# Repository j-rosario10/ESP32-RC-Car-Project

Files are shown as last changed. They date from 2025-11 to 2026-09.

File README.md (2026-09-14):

# BMW M2 RC Car

An ESP32-based RC vehicle inspired by the BMW M2 Competition, combining mechanical design, embedded motor control, and a game-style web dashboard into a single mechatronics system.

---

## 🔧 Technical Overview

- Designed a custom BMW M2-inspired chassis in SolidWorks, accounting for motor mounting, steering geometry, electronics placement, and manufacturability, then validated the structure with FEA before printing.
- Implemented dual DC motor drive and steering servo control using an ESP32, H-bridge motor drivers, and PWM control logic programmed in Arduino C++.
- Added a torque vectoring layer that biases drive torque between the left and right motors based on steering input, tightening corner entry without a mechanical differential.
- Implemented regenerative braking that shorts the motor terminals through the H-bridge under deceleration, recovering energy back into the pack instead of coasting or hard-braking.
- Developed an ESP32-hosted web dashboard using HTML, CSS, and JavaScript for real-time wireless vehicle control and live telemetry.
- Integrated ultrasonic obstacle detection directly into the motor control loop to automatically prevent collisions during forward motion.
  
---

## ⚙️ Key Features

- Independent left and right motor control with real-time differential steering and smooth acceleration and braking behaviour.
- Steering-dependent torque vectoring, with the bias curve exposed as a tunable parameter rather than hardcoded.
- Regenerative braking on throttle release and on brake input, with the recovered current visible live on the dashboard.
- Fail-safe stop logic that halts the vehicle when control input is released or the connection is lost.
- Ultrasonic obstacle detection that continuously monitors distance ahead and blocks forward motion within a safety threshold.
- ESP32-hosted, game-style dashboard with live speed visualization, steering indicators, drive state feedback, and pedal-style controls.
- Drift mode toggle that increases steering aggressiveness and relaxes the torque bias, reflected visually in the dashboard.
- Modular ESP32-CAM integration providing live video feedback without impacting motor responsiveness.
- Lightweight, non-blocking networking architecture using REST-style endpoints for control and telemetry.

---

## 📸 Project Media

<p align="center">
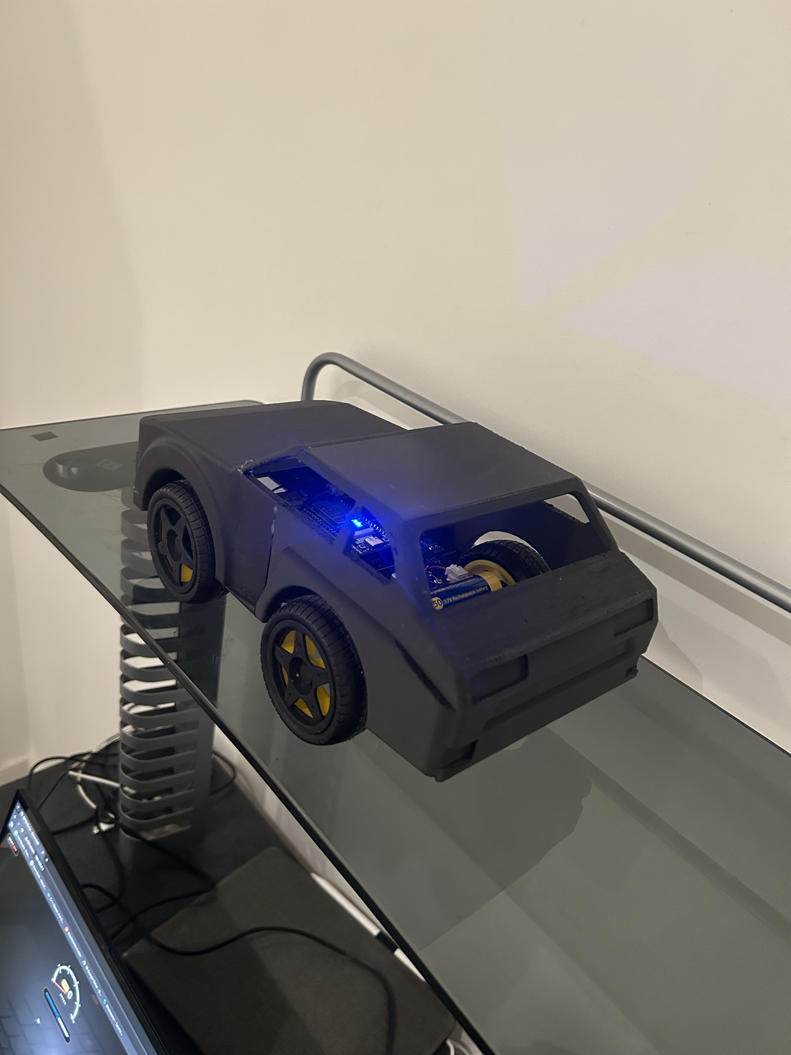
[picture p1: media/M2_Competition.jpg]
  
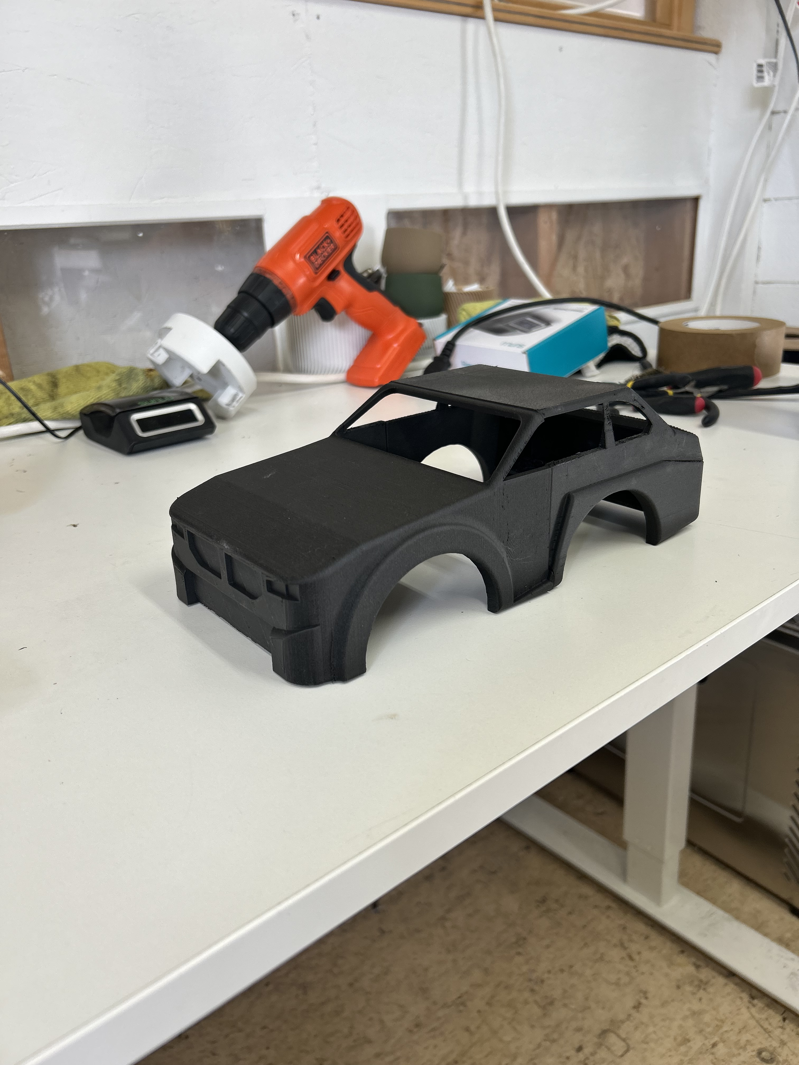
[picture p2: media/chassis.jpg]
  
</p>

<p align="center">
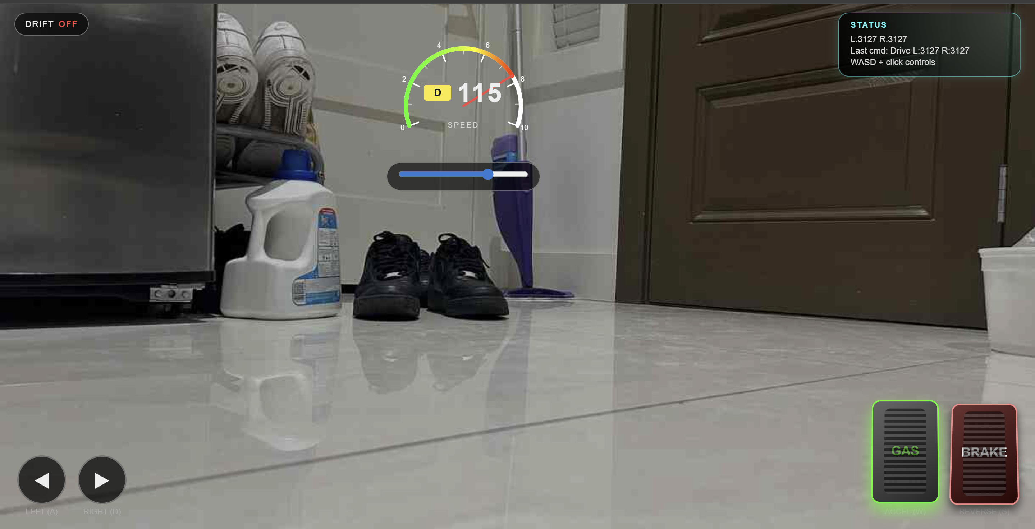
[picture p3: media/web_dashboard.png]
  
</p>

<p align="center">
  <i>BMW M2 inspired exterior, SolidWorks chassis design, and full screen web based control dashboard</i>
</p>

---

## 🎥 Video Demonstration

The video below shows live driving, dashboard interaction, steering response, and integrated obstacle detection.

▶ **Watch the RC Car Demonstration Video**  
https://drive.google.com/file/d/1aE3MejNEvwfQ_U80hKvikGiKrMmLiO1q/view?usp=sharing

---

## 🧠 System Architecture

- Mechanical  
  SolidWorks CAD chassis designed for compact packaging and structural rigidity, checked under load with FEA and printed in-house.

- Embedded  
  ESP32 microcontroller handling motor control, torque distribution, regenerative braking, sensing, networking, and camera streaming.

- Software  
  Modular C++ codebase developed in VS Code with PlatformIO, separating vehicle control, torque and brake logic, dashboard logic, and camera handling.

- Networking  
  ESP32 configured as a self-contained Wi-Fi access point with HTTP endpoints for control, telemetry, and video streaming.

---

## 🚀 Future Improvements

- Closed-loop speed control using wheel encoders, which would also let the regen braking target a set deceleration rate instead of a fixed duty.
- Vision-based obstacle detection using the onboard camera.
- Autonomous navigation behaviours built on the existing safety logic.
- Mobile-optimized dashboard layout.

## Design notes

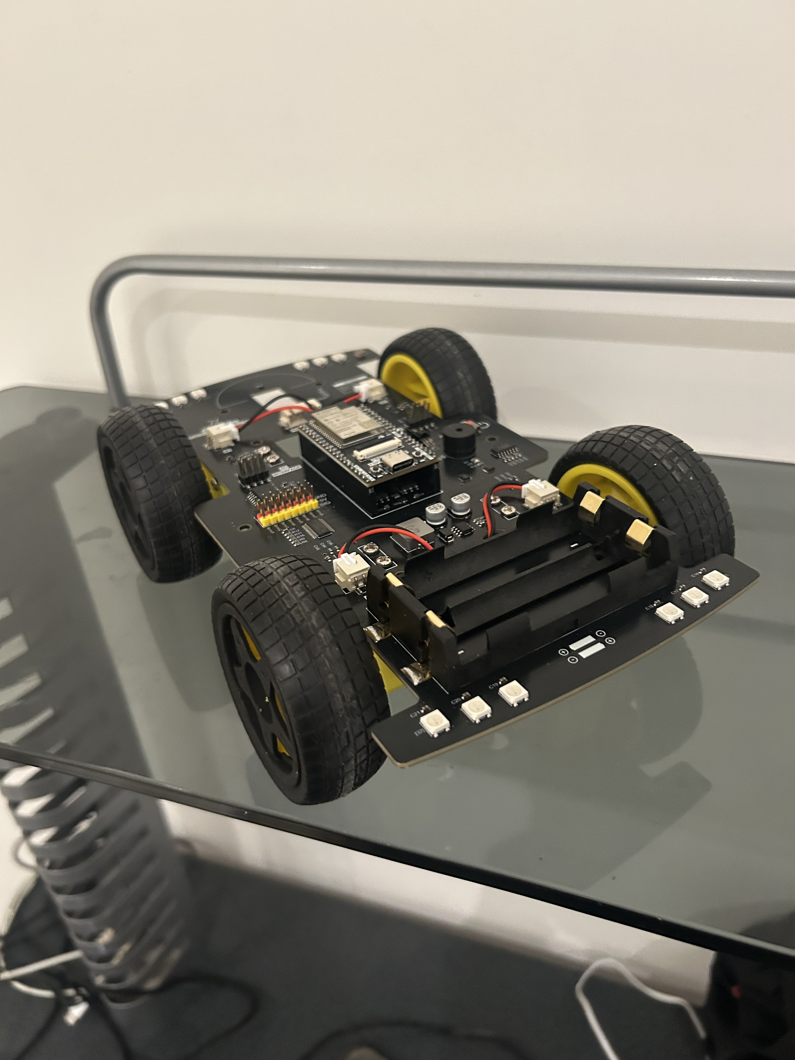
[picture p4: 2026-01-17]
media/hardware.jpg

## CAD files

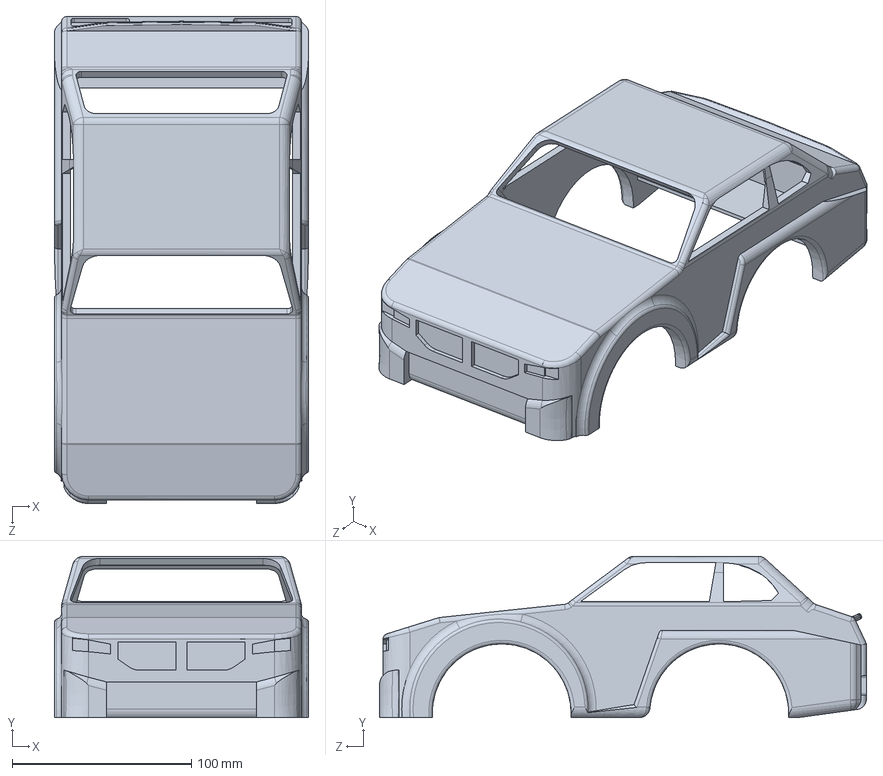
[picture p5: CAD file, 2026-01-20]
CAD/RC Car Shell_V2.SLDPRT
142.0 x 90.1 x 272.0 mm

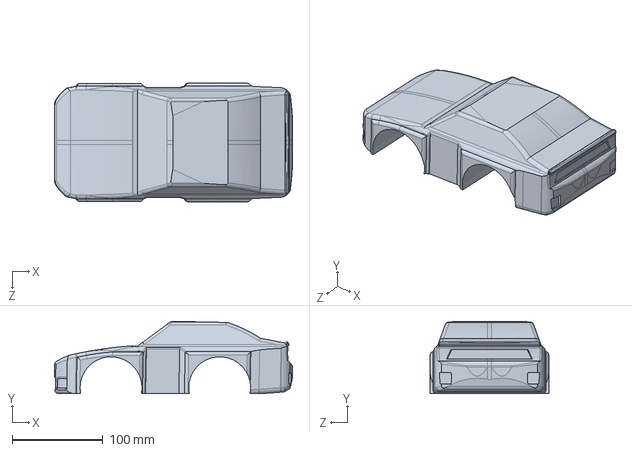
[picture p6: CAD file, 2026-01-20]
CAD/RC Car Shell.SLDPRT
261.9 x 79.8 x 130.5 mm

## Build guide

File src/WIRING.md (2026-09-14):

# Wiring and bring-up

## The shared bus

GPIO 13 and 14 already run to the PCA9685. The gyro and current sensor join
those same two wires. You are not adding new pins for either sensor.

Each chip has a different address so they don't collide:

| Chip | Address |
|---|---|
| PCA9685 (motors) | 0x5F |
| MPU6050 (gyro) | 0x68 |
| INA226 (current) | 0x40 |

## MPU6050 gyro

| Pin | To |
|---|---|
| VCC | **3.3V** — not 5V |
| GND | GND |
| SDA | GPIO 13 |
| SCL | GPIO 14 |
| AD0 | GND, or leave it |

Mount it flat, near the middle of the car, Z axis pointing up, and screw it
down properly. Foam tape lets it vibrate and motor buzz shows up as fake
rotation in the readings.

**Before trusting it:** uncomment `Sensors::gyroSignTest()` in `setup()`,
flash, and rotate the car by hand. One direction should be consistently
positive, the other consistently negative. If it's backwards, change
`GYRO_Z_SIGN` to `-1.0f` in `config.h`. Don't remount the chip.

## INA226 current sensor

This one goes *in* the power path, not on a header. Cut the positive battery
wire and put the sensor in the gap:

```
Battery + ──→ [IN+]  INA226  [IN−] ──→ board power in
```

IN+ faces the battery, IN− faces the car. Backwards and charging reads as
draining.

| Pin | To |
|---|---|
| VCC | 3.3V |
| GND | GND |
| SDA | GPIO 13 |
| SCL | GPIO 14 |

**Check your shunt.** Lots of cheap boards ship with a 0.1 ohm shunt rated
under 1A, which four motors will cook. Get 0.01 ohm or lower, then put the
real value in `SHUNT_OHMS` in `config.h`. Wrong value means every reading is
wrong by the same factor, silently.

## DRV8871 regen driver

One motor only. Leave the other three on the PCA9685 so the car still drives
normally while you experiment.

| Pin | To |
|---|---|
| IN1 | GPIO 25 |
| IN2 | GPIO 26 |
| VM | Battery + (downstream of the INA226) |
| GND | GND |
| OUT1 / OUT2 | The motor's two wires |

Unplug that motor from the old driver first. One motor, one driver, never both.

Avoid GPIO 0, 2, 12 and 15 if you change pins — the ESP32 reads those at boot
and pulling them wrong stops it starting. 25, 26, 27, 32 are safe.

## Bring-up order

Flash and test after each step rather than doing it all at once.

1. **Code only, no new parts.** Motor braking and 1000Hz PWM work with the
   hardware you already have. Confirm the car stops hard instead of lurching
   into reverse.
2. **Gyro.** Run the sign test. Then set `YAW_KP = 0` in `config.h` and drive —
   watch target vs actual on the dashboard without any correction happening.
   Only once those numbers look sane, raise KP.
3. **Current sensor.** Watch live watts while driving. Accelerating should be
   a big positive number, coasting near zero. Confirm the sign before you
   trust the energy totals.
4. **Regen driver.** Test at low speed, at about half battery charge, watching
   pack voltage. If it climbs past 8.3V, stop.

## Tuning YAW_KP

Start at 0. Raise it in steps of about 0.001. When the car starts weaving side
to side on a straight, you've gone too far — drop back about 30%.

`YAW_TARGET_GAIN` is the other knob. If actual yaw never gets anywhere near
target even at full correction, the target is unrealistic — lower it.

## Watch the overrun counter

The dashboard shows how many times the loop missed its 5ms slot. A handful at
startup is fine. If it climbs steadily while driving, the loop is doing more
work than it has time for — usually I2C traffic. Drop `LOOP_HZ` to 100 or read
the gyro every other cycle.

## Safety

- Regen testing at half charge, never straight off the charger.
- Watch pack voltage. Two full cells sit at 8.4V and pushing above that is
  not safe.
- The failsafe stops the car if the browser goes quiet for 300ms. Test it
  early — drive slowly, close the tab, confirm the car stops.

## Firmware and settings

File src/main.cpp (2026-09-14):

// BMW M2 RC car - ESP32 firmware
//
// Sections in order:
//   1  config     temp numbers
//   2  motors     talking to the motor chip, including braking
//   3  sensors    gyro and battery current
//   4  regen      the fast switching that charges the battery while braking
//   5  control    the loop that runs 200 times a second and does the driving
//   6  web        the Wi-Fi network and the web page
//
// The big idea: the browser does NOT drive the car. It only reports which
// keys you're holding. All the actual decisions happen in section 5, on the
// ESP32. That's because Wi-Fi delay is unpredictable - a message might take
// 5 milliseconds or 200 - and anything automatic needs steady timing.

#include <Arduino.h>
#include <Wire.h>
#include <WiFi.h>
#include <WebServer.h>
#include <PCA9685.h>
#include <Adafruit_MPU6050.h>
#include <Adafruit_Sensor.h>
#include <INA226.h>

#include "page.h"

// ===========================================================================
// 1  CONFIG
// ===========================================================================

// These two pins are fixed by the Freenove board, so don't change them.
// All three chips share the same two wires and take turns talking.
static constexpr int I2C_SDA = 13;
static constexpr int I2C_SCL = 14;
static constexpr uint32_t I2C_CLOCK_HZ = 400000;   // 4x the default speed,
                                                   // because chatting to the
                                                   // chips is the slowest part
                                                   // of each loop

// Each chip has its own address so the ESP32 knows who it's talking to.
static constexpr uint8_t ADDR_PCA9685 = 0x5F;
static constexpr uint8_t ADDR_MPU6050 = 0x68;
static constexpr uint8_t ADDR_INA226  = 0x40;

// The kit sets this to 50 because it shares the chip with steering servos.
// We have no servos, so we can turn it right up. Smoother, and free.
static constexpr int MOTOR_PWM_FREQ = 1000;
static constexpr int MOTOR_MAX = 4095;             // full speed

// Don't use pins 0, 2, 12 or 15 - the ESP32 checks those when it starts up
// and pulling them the wrong way stops it booting.
static constexpr int REGEN_IN1_PIN = 25;
static constexpr int REGEN_IN2_PIN = 26;
static constexpr int REGEN_PWM_FREQ = 20000;       // 20,000 switches a second.
                                                   // Too fast to hear, and fast
                                                   // enough for the pumping
                                                   // trick to work.
static constexpr int REGEN_PWM_BITS = 10;

// How many times a second the control loop runs. 200 was chosen because it's
// as fast as we can go before talking to the chips takes too long.
static constexpr int   LOOP_HZ = 200;
static constexpr float LOOP_DT = 1.0f / LOOP_HZ;   // 5 milliseconds
static constexpr uint32_t INPUT_TIMEOUT_MS = 300;  // silence this long = stop

// A key is only on or off, but steering is an amount. So we use TIME as the
// missing information: tap for a little, hold for a lot.
// Letting go is faster than holding, so the car straightens up promptly.
static constexpr float STEER_RISE_RATE = 2.0f;     // half a second to full lock
static constexpr float STEER_FALL_RATE = 4.0f;
static constexpr float THROTTLE_RISE_RATE = 1.5f;
static constexpr float THROTTLE_FALL_RATE = 2.5f;
static constexpr float BRAKE_RISE_RATE = 3.0f;
static constexpr float BRAKE_FALL_RATE = 6.0f;

// Drift mode just lets the steering build up further than normal.
static constexpr float STEER_LIMIT_NORMAL = 0.60f;
static constexpr float STEER_LIMIT_DRIFT  = 1.00f;

// How fast the car should spin around at full steering and full speed,
// in degrees per second. Found by driving it and seeing what it can do.
static constexpr float YAW_TARGET_GAIN = 180.0f;

// How hard the car corrects itself. START AT 0 and raise it slowly. When the
// car starts weaving side to side on a straight, that's too much - back off.
static constexpr float YAW_KP = 0.004f;

// The most the car is allowed to correct. Without this, on a slippery floor
// it would push harder and harder and just spin on the spot.
static constexpr float YAW_CORRECTION_LIMIT = 0.45f;

// Whether "turning right" reads as a positive or negative number depends on
// which way up you mounted the gyro. Run the test in setup(), and if it's
// backwards change this to -1.0f. Easier than remounting the chip.
static constexpr float GYRO_Z_SIGN = 1.0f;

// Anything smaller than this is just the motors shaking the car, not the car
// actually turning. Ignoring it stops the controller twitching.
static constexpr float GYRO_DEADBAND_DPS = 1.5f;

// There are no encoders on this car, so we can't measure speed. Instead we
// guess: assume the car catches up to the throttle with a delay. It's wrong
// if the wheels spin, but we only need a rough fast-or-slow.
static constexpr float SPEED_RISE_TAU = 0.8f;      // seconds to get up to speed
static constexpr float SPEED_FALL_TAU = 1.2f;      // coasts down slower
static constexpr float SPEED_BRAKE_TAU = 0.4f;     // braking drops it fast

// Two lithium cells fully charged sit at 8.4V. A full battery has no room for
// more charge, so we stop regen before we get there. Real electric cars do
// the same thing - it's why regen feels weak right after charging.
static constexpr float PACK_REGEN_CUTOFF_VOLTS = 8.30f;

// CHECK YOUR BOARD. Lots of cheap current sensors come with a 0.1 ohm shunt
// rated for under 1 amp, and four motors will cook it. You want 0.01 or less.
// If this number doesn't match your board, every reading is wrong.
static constexpr float SHUNT_OHMS = 0.010f;
static constexpr float SHUNT_MAX_AMPS = 8.0f;

// The car makes its own Wi-Fi network, so it works anywhere with no router.
static const char* AP_SSID = "ESP32-RC-Car";
static const char* AP_PASS = "";

// ===========================================================================
// 2  MOTORS
// ===========================================================================

// These are channel numbers on the PCA9685 chip, NOT ESP32 pins. Easy to mix
// up. Each motor uses two channels, because the driver needs two signals to
// know both how fast to go and which direction.
static constexpr uint8_t M1_IN1 = 15, M1_IN2 = 14;
static constexpr uint8_t M2_IN1 = 9,  M2_IN2 = 8;
static constexpr uint8_t M3_IN1 = 12, M3_IN2 = 13;
static constexpr uint8_t M4_IN1 = 10, M4_IN2 = 11;

// If a wheel spins the wrong way after you rewire something, flip its
// number to -1 here instead of changing any logic.
static constexpr int M1_DIR = 1, M2_DIR = 1, M3_DIR = 1, M4_DIR = 1;

static PCA9685 pca;

// Remembers what we last sent to each channel. Talking to the motor chip is
// slow, and most of the time only a couple of channels actually change, so
// skipping the rest gives us back a big chunk of each loop.
static int lastWritten[16];

static int clampMotor(int s) {
    if (s < -MOTOR_MAX) return -MOTOR_MAX;
    if (s >  MOTOR_MAX) return  MOTOR_MAX;
    return s;
}

static void writeChannel(uint8_t ch, int value) {
    if (lastWritten[ch] == value) return;      // nothing changed, skip it
    pca.setChannelPulseWidth(ch, value);
    lastWritten[ch] = value;
}

// The motor driver has four possible states, and the original code only ever
// used three of them:
//
//   speed / 0        forward
//   0 / speed        reverse
//   0 / 0            coast - motor spins freely
//   high / high      BRAKE - the two motor wires get joined together
//
// That last one is the whole trick behind motor braking. You don't connect
// any wires yourself. The switches are already inside the chip - the old code
// just never asked for them.
static void driveChannels(uint8_t in1, uint8_t in2, int speed) {
    speed = clampMotor(speed);

    if (speed >= 0) { writeChannel(in1, speed);  writeChannel(in2, 0); }
    else            { writeChannel(in1, 0);      writeChannel(in2, -speed); }
}

// Sending the same value to both inputs joins the motor wires together.
// At full value it's permanently joined and brakes hard. At half, it spends
// half its time joined and half coasting, which gives about half the braking.
// That's how you get a brake with pressure levels out of an on/off chip.
static void brakeChannels(uint8_t in1, uint8_t in2, int strength) {
    if (strength < 0) strength = -strength;
    if (strength > MOTOR_MAX) strength = MOTOR_MAX;

    writeChannel(in1, strength);
    writeChannel(in2, strength);
}

// m1 and m2 are the right side. m3 and m4 are the left side.
static void motorsMove(int m1, int m2, int m3, int m4) {
    driveChannels(M1_IN1, M1_IN2, M1_DIR * clampMotor(m1));
    driveChannels(M2_IN1, M2_IN2, M2_DIR * clampMotor(m2));
    driveChannels(M3_IN1, M3_IN2, M3_DIR * clampMotor(m3));
    driveChannels(M4_IN1, M4_IN2, M4_DIR * clampMotor(m4));
}

static void motorsBrake(int strength) {
    brakeChannels(M1_IN1, M1_IN2, strength);
    brakeChannels(M2_IN1, M2_IN2, strength);
    brakeChannels(M3_IN1, M3_IN2, strength);
    brakeChannels(M4_IN1, M4_IN2, strength);
}

static void motorsBegin() {
    for (int i = 0; i < 16; i++) lastWritten[i] = -1;   // force the first write

    Wire.begin(I2C_SDA, I2C_SCL);
    Wire.setClock(I2C_CLOCK_HZ);

    // The motor chip powers up asleep. This wakes it. The library is supposed
    // to do this but it doesn't always work, so we do it by hand first.
    Wire.beginTransmission(ADDR_PCA9685);
    Wire.write(0x00);
    Wire.write(0x00);
    Wire.endTransmission();

    pca.setupSingleDevice(Wire, ADDR_PCA9685);
    pca.setToFrequency(MOTOR_PWM_FREQ);

    motorsMove(0, 0, 0, 0);
}

// ===========================================================================
// 3  SENSORS
// ===========================================================================
// Both sensors are optional. If one isn't plugged in, the car still drives -
// it just turns off the feature that needed it, instead of refusing to start.

static Adafruit_MPU6050 mpu;
static INA226 ina(ADDR_INA226, &Wire);

static bool gyroOK = false, inaOK = false;
static float gyroZeroOffset = 0.0f;     // the gyro's own built-in error
static float yawRateDps = 0.0f;         // how fast the car is turning
static float packV = 0.0f, packA = 0.0f, packW = 0.0f;
static float joulesOut = 0.0f, joulesIn = 0.0f;

// We only read the current sensor every 10th loop, so 20 times a second.
// Reading it is slow, and battery current doesn't change much in 5ms anyway.
static uint8_t inaSkip = 0;
static uint32_t lastEnergyUs = 0;

static void sensorsBegin() {
    // The two wires are already switched on by motorsBegin(), so we just
    // join the conversation. That's why the order in setup() matters.

    if (mpu.begin(ADDR_MPU6050, &Wire)) {
        gyroOK = true;

        // The narrowest range the chip offers. The car never turns faster
        // than this, and a narrow range means finer detail on small numbers -
        // which is exactly what the controller reacts to.
        mpu.setGyroRange(MPU6050_RANGE_250_DEG);
        mpu.setAccelerometerRange(MPU6050_RANGE_4_G);

        // A smoothing filter inside the chip. 21Hz is the sweet spot: enough
        // to hide motor vibration, not so much that readings arrive late.
        // Late readings make the controller unstable.
        mpu.setFilterBandwidth(MPU6050_BAND_21_HZ);

        Serial.println("[sensors] MPU6050 found");
    } else {
        Serial.println("[sensors] no MPU6050 - torque vectoring disabled");
    }

    if (ina.begin()) {
        inaOK = true;
        ina.setMaxCurrentShunt(SHUNT_MAX_AMPS, SHUNT_OHMS);
        Serial.println("[sensors] INA226 found");
    } else {
        Serial.println("[sensors] no INA226 - regen will run blind");
    }

    lastEnergyUs = micros();
}

// Every gyro reports a small wrong number even when perfectly still, and it's
// different for every chip. So we sit still, take 500 readings, average them,
// and subtract that from everything afterwards.
//
// One reading isn't enough because the noise is about the same size as the
// error we're trying to find. Averaging cancels the noise out.
//
// THE CAR MUST BE STILL while this runs.
static void calibrateGyro(uint16_t samples = 500) {
    if (!gyroOK) return;

    Serial.println("[sensors] calibrating - keep the car still");

    double sum = 0.0;
    for (uint16_t i = 0; i < samples; i++) {
        sensors_event_t a, g, t;
        mpu.getEvent(&a, &g, &t);
        sum += g.gyro.z;
        delay(3);
    }

    // The library gives radians per second; we want degrees per second.
    gyroZeroOffset = (float)(sum / samples) * 57.2958f;

    Serial.print("[sensors] gyro offset: ");
    Serial.print(gyroZeroOffset, 3);
    Serial.println(" deg/s");
}

static void sensorsUpdate() {
    if (gyroOK) {
        sensors_event_t a, g, t;
        mpu.getEvent(&a, &g, &t);

        float dps = (g.gyro.z * 57.2958f) - gyroZeroOffset;
        dps *= GYRO_Z_SIGN;

        // Tiny readings are the motors shaking the car, not the car turning.
        if (dps > -GYRO_DEADBAND_DPS && dps < GYRO_DEADBAND_DPS) dps = 0.0f;

        yawRateDps = dps;
    }

    if (inaOK) {
        if (++inaSkip >= 10) {
            inaSkip = 0;
            packV = ina.getBusVoltage();
            packA = ina.getCurrent();      // negative means charging
            packW = packV * packA;
        }

        // Energy is just power multiplied by time, added up as we go.
        // We do this every loop, even though the reading only updates every
        // 10th, so the time part stays accurate.
        uint32_t now = micros();
        float dt = (now - lastEnergyUs) / 1000000.0f;
        lastEnergyUs = now;

        // The microsecond timer wraps around every 70 minutes and gives a
        // nonsense value when it does. This throws that one reading away.
        if (dt > 0.0f && dt < 0.5f) {
            if (packW > 0) joulesOut += packW * dt;
            else           joulesIn  += (-packW) * dt;
        }
    }
}

// Run this once after mounting the gyro. Rotate the car by hand and watch the
// numbers: one direction should be positive, the other negative. If it's
// backwards, change GYRO_Z_SIGN above rather than remounting the chip.
static void gyroSignTest() {
    if (!gyroOK) { Serial.println("[test] no gyro"); return; }

    Serial.println("[test] rotate the car by hand for 10s");

    uint32_t until = millis() + 10000;
    while (millis() < until) {
        sensorsUpdate();
        Serial.print("yaw: ");
        Serial.print(yawRateDps, 1);
        Serial.println(" deg/s");
        delay(100);
    }
}

// ===========================================================================
// 4  REGEN
// ===========================================================================
// This section exists because the motor chip is too slow. It can switch about
// 1,500 times a second. Regen needs about 20,000. The ESP32 itself can do
// that easily, so one motor gets its own driver board wired straight to two
// ESP32 pins, skipping the slow chip entirely.
//
// How the charging works:
//
//   Both pins HIGH -> the motor's two wires are joined together. Electricity
//                     builds up inside the motor's coil. The battery isn't
//                     part of this at all yet.
//
//   Both pins LOW  -> the connection breaks. That built-up electricity has
//                     nowhere to go, so it forces itself out at a higher
//                     voltage - high enough to reach the battery.
//
// Build, release, build, release, 20,000 times a second. It's a pump. How
// much of each cycle is spent building is how hard you brake.
//
// Both pins get the exact same signal, which is why this is only a few lines.

static constexpr int REGEN_CH1 = 4;    // channels 0-3 are often used by other
static constexpr int REGEN_CH2 = 5;    // libraries, so we start at 4
static constexpr int REGEN_DUTY_MAX = (1 << REGEN_PWM_BITS) - 1;

static void regenWrite(int duty) {
#if ESP_ARDUINO_VERSION_MAJOR >= 3
    ledcWrite(REGEN_IN1_PIN, duty);
    ledcWrite(REGEN_IN2_PIN, duty);
#else
    ledcWrite(REGEN_CH1, duty);
    ledcWrite(REGEN_CH2, duty);
#endif
}

// duty is 0 to 1, and more is NOT always better:
//   0.0   coasting, nothing happens
//   0.3   light braking, and most of the energy reaches the battery
//   1.0   the motor stays joined the whole time, so it brakes hard but the
//         electricity never gets released - all drag, no charge
// The useful range is about 0.2 to 0.7, which is why the controller caps it.
static void regenSetDuty(float duty) {
    if (duty < 0.0f) duty = 0.0f;
    if (duty > 1.0f) duty = 1.0f;
    regenWrite((int)(duty * REGEN_DUTY_MAX));
}

static void regenCoast() { regenWrite(0); }

static void regenBegin() {
    // Newer versions of the ESP32 software renamed these functions, so we
    // handle both. Saves you a confusing error if you update.
#if ESP_ARDUINO_VERSION_MAJOR >= 3
    ledcAttach(REGEN_IN1_PIN, REGEN_PWM_FREQ, REGEN_PWM_BITS);
    ledcAttach(REGEN_IN2_PIN, REGEN_PWM_FREQ, REGEN_PWM_BITS);
#else
    ledcSetup(REGEN_CH1, REGEN_PWM_FREQ, REGEN_PWM_BITS);
    ledcSetup(REGEN_CH2, REGEN_PWM_FREQ, REGEN_PWM_BITS);
    ledcAttachPin(REGEN_IN1_PIN, REGEN_CH1);
    ledcAttachPin(REGEN_IN2_PIN, REGEN_CH2);
#endif
    regenCoast();
}

// ===========================================================================
// 5  CONTROL
// ===========================================================================

// What the browser sends us: which keys are held down. Not motor commands.
// The old version had the browser do the maths and send finished numbers,
// which meant the driving decisions were being made on the far side of a
// Wi-Fi connection. Fine for a person pressing keys, useless for anything
// that has to react to the car.
struct Input {
    bool w = false, a = false, s = false, d = false, drift = false;
    uint32_t lastSeenMs = 0;
};

// Everything the loop works out gets published here, not just what the
// dashboard shows. Being able to log what the car wanted versus what it did
// is how you tune the controller and how you measure the regen.
struct Telemetry {
    float steer, throttle, brake, speedEst;
    float yawTarget, yawActual, yawError, correction;
    float volts, amps, watts, joulesOut, joulesIn;
    uint32_t overruns;
    bool failsafe;
};

// Two parts of the program touch these at the same time, so they need
// protecting or you get half-updated values. This is the quick kind of lock -
// the web page must never be able to hold up the motors.
static portMUX_TYPE stateMux = portMUX_INITIALIZER_UNLOCKED;
static Input     sharedInput;
static Telemetry sharedTelem;

// Only the control loop touches these, so they don't need protecting.
static float steer = 0.0f, throttle = 0.0f, brake = 0.0f, speedEst = 0.0f;
static uint32_t overrunCount = 0;

// Moves a value a little bit toward a target, without overshooting it.
static float rampToward(float value, float target, float rate, float dt) {
    float step = rate * dt;

    if (value < target)      { value += step; if (value > target) value = target; }
    else if (value > target) { value -= step; if (value < target) value = target; }
    return value;
}

// HOLD TO BUILD
// A key is on or off, but steering is an amount. So we use how long you hold
// it: tap for a little, hold for a lot.
//
// This has to happen here on the car, not in the browser. If the browser did
// the ramping, every step of it would have to travel over Wi-Fi, and the ramp
// would end up as jerky as the connection.
static void updateInputs(const Input& in) {
    float limit = in.drift ? STEER_LIMIT_DRIFT : STEER_LIMIT_NORMAL;

    // Letting go fades faster than holding builds, so the car straightens up
    // quickly instead of carrying steering into whatever you do next.
    if (in.a && !in.d)      steer = rampToward(steer, -limit, STEER_RISE_RATE, LOOP_DT);
    else if (in.d && !in.a) steer = rampToward(steer,  limit, STEER_RISE_RATE, LOOP_DT);
    else                    steer = rampToward(steer,  0.0f,  STEER_FALL_RATE, LOOP_DT);

    // S is a proper brake now. It used to subtract from throttle, which meant
    // pressing brake actually commanded reverse - spending battery power to
    // fight the motors instead of taking power out of them.
    throttle = in.w ? rampToward(throttle, 1.0f, THROTTLE_RISE_RATE, LOOP_DT)
                    : rampToward(throttle, 0.0f, THROTTLE_FALL_RATE, LOOP_DT);

    brake = in.s ? rampToward(brake, 1.0f, BRAKE_RISE_RATE, LOOP_DT)
                 : rampToward(brake, 0.0f, BRAKE_FALL_RATE, LOOP_DT);
}

// SPEED GUESS
// This is a guess, not a measurement - there are no encoders on the wheels.
// We assume the car catches up to whatever throttle you asked for, with a
// delay. It's wrong if the wheels are spinning, but the steering maths below
// only needs a rough idea of fast or slow.
static void updateSpeedEstimate() {
    float target = fabsf(throttle);
    float tau;                        // how many seconds to catch up

    if (brake > 0.05f)          tau = SPEED_BRAKE_TAU;
    else if (target > speedEst) tau = SPEED_RISE_TAU;
    else                        tau = SPEED_FALL_TAU;

    if (brake > 0.05f) target = 0.0f;

    // Move part of the way toward the target each loop. Small tau means it
    // catches up quickly.
    float alpha = LOOP_DT / (tau + LOOP_DT);
    speedEst += (target - speedEst) * alpha;

    if (speedEst < 0.0f) speedEst = 0.0f;
    if (speedEst > 1.0f) speedEst = 1.0f;
}
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
void loop() {
    // Web server only. Deliberately no motor code here - the driving happens
    // in the control loop on the other processor at a steady rate, so
    // whatever the web server is busy with can't affect how the car behaves.
    server.handleClient();
}

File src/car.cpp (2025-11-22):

#include "car.h"

#include <Wire.h>
#include <PCA9685.h>

namespace Car {

// ==== PCA9685 + wiring config (from Freenove) ====
static constexpr int PCA9685_SDA      = 13;
static constexpr int PCA9685_SCL      = 14;
static constexpr uint8_t PCA9685_ADDR = 0x5F;
static constexpr int SERVO_FREQUENCY  = 50;   // Hz

// Motor speed range (same as header)
static constexpr int SPEED_MIN = MOTOR_SPEED_MIN;
static constexpr int SPEED_MAX = MOTOR_SPEED_MAX;

// PCA9685 channel mapping for motors (from Freenove_4WD_Car_For_ESP32.cpp)
// These numbers are PCA9685 output channels, NOT ESP32 GPIO.
static constexpr uint8_t PIN_MOTOR_M1_IN1 = 15;
static constexpr uint8_t PIN_MOTOR_M1_IN2 = 14;
static constexpr uint8_t PIN_MOTOR_M2_IN1 = 9;
static constexpr uint8_t PIN_MOTOR_M2_IN2 = 8;
static constexpr uint8_t PIN_MOTOR_M3_IN1 = 12;
static constexpr uint8_t PIN_MOTOR_M3_IN2 = 13;
static constexpr uint8_t PIN_MOTOR_M4_IN1 = 10;
static constexpr uint8_t PIN_MOTOR_M4_IN2 = 11;

// Direction (1 or -1) in case you want to flip later
static constexpr int MOTOR_1_DIRECTION = 1;
static constexpr int MOTOR_2_DIRECTION = 1;
static constexpr int MOTOR_3_DIRECTION = 1;
static constexpr int MOTOR_4_DIRECTION = 1;

static PCA9685 pca9685;

static int clampSpeed(int s) {
    if (s < SPEED_MIN) return SPEED_MIN;
    if (s > SPEED_MAX) return SPEED_MAX;
    return s;
}

// Low-level: set a single motor via its two PCA9685 channels
static void setMotorChannels(uint8_t ch_in1, uint8_t ch_in2, int speed) {
    speed = clampSpeed(speed);

    if (speed >= 0) {
        // positive direction: IN1 = speed, IN2 = 0
        pca9685.setChannelPulseWidth(ch_in1, speed);
        pca9685.setChannelPulseWidth(ch_in2, 0);
    } else {
        // negative direction: IN1 = 0, IN2 = |speed|
        speed = -speed;
        pca9685.setChannelPulseWidth(ch_in1, 0);
        pca9685.setChannelPulseWidth(ch_in2, speed);
    }
}

void begin() {
    // Initialize I2C on the same pins as Freenove
    Wire.begin(PCA9685_SDA, PCA9685_SCL);

    // Set MODE1 to 0x00 (normal mode), like Freenove does
    Wire.beginTransmission(PCA9685_ADDR);
    Wire.write(0x00);
    Wire.write(0x00);
    Wire.endTransmission();

    // Initialize the PCA9685 driver
    pca9685.setupSingleDevice(Wire, PCA9685_ADDR);
    pca9685.setToFrequency(SERVO_FREQUENCY);

    stop();
}

void move(int m1, int m2, int m3, int m4) {
    // Apply motor direction constants + clamp
    m1 = MOTOR_1_DIRECTION * clampSpeed(m1);
    m2 = MOTOR_2_DIRECTION * clampSpeed(m2);
    m3 = MOTOR_3_DIRECTION * clampSpeed(m3);
    m4 = MOTOR_4_DIRECTION * clampSpeed(m4);

    // Use same pattern as Freenove's Motor_Move
    setMotorChannels(PIN_MOTOR_M1_IN1, PIN_MOTOR_M1_IN2, m1);
    setMotorChannels(PIN_MOTOR_M2_IN1, PIN_MOTOR_M2_IN2, m2);
    setMotorChannels(PIN_MOTOR_M3_IN1, PIN_MOTOR_M3_IN2, m3);
    setMotorChannels(PIN_MOTOR_M4_IN1, PIN_MOTOR_M4_IN2, m4);
}

void stop() {
    move(0, 0, 0, 0);
}

void forward(int speed) {
    speed = clampSpeed(speed);
    move(speed, speed, speed, speed);
}

void backward(int speed) {
    speed = clampSpeed(speed);
    move(-speed, -speed, -speed, -speed);
}

void turnLeft(int speed) {
    speed = clampSpeed(speed);
    move(-speed, -speed, speed, speed);
}

void turnRight(int speed) {
    speed = clampSpeed(speed);
    move(speed, speed, -speed, -speed);
}

} // namespace Car

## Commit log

2025-11-22 Initial commit: working ESP32 car platformIO project
2025-11-30 Add Drift Mode, speed slider, RPM bar, gear indicator, and full v1 game-style dashboard
    [main.cpp]
2025-11-30 UI Update: red needle, restored RPM label spacing, fixed clipping, slider border
    [main.cpp]
